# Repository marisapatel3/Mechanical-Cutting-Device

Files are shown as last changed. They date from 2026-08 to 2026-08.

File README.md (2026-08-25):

# Mechanical Cutting Device: Adaptive Fold-Over Slicer

McMaster ENGINEER 1P13, Mar 2022 – Apr 2022.

Ergonomic fold-over slicer designed for a client with Ehlers Danlos Syndrome to reduce joint strain and lateral hand movement during food preparation.

`Autodesk Inventor` `3D Printing` `Woodworking` `Assistive Design` `PLA` 

<p align="center">
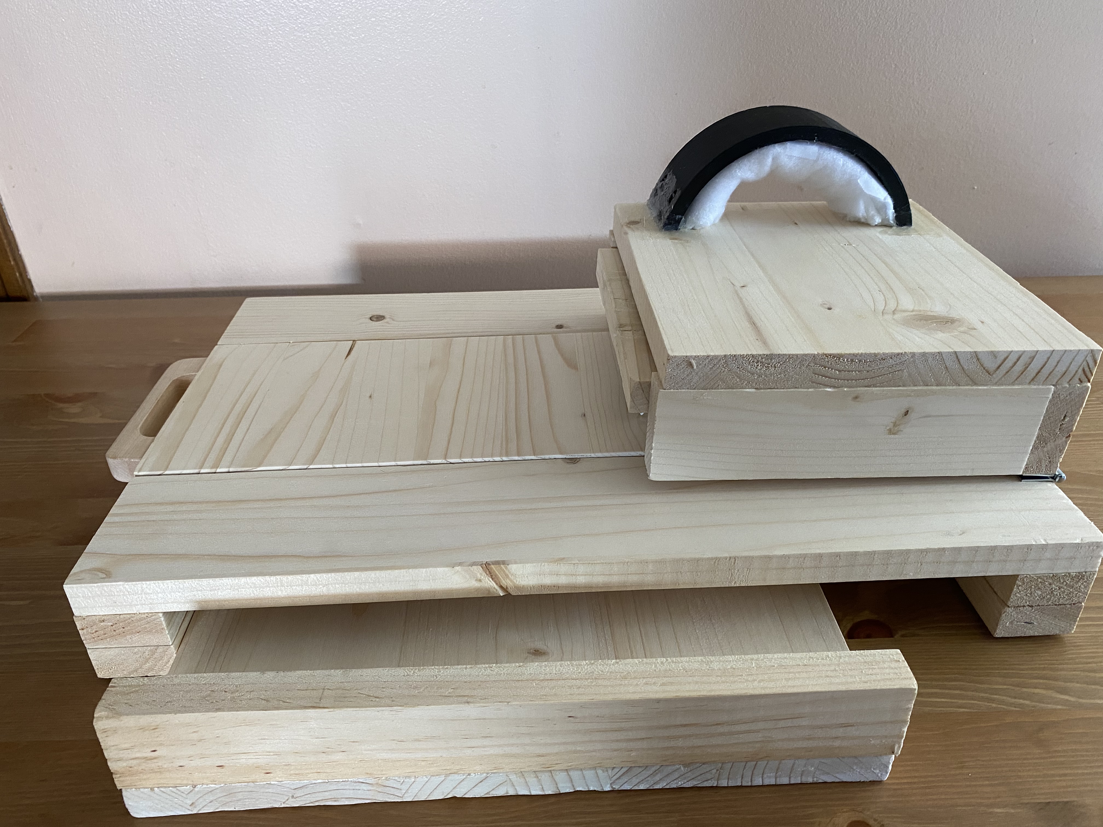
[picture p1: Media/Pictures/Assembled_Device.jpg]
Assembled device
<br>
<em>Fully Assembled Cutting Device with the Cutting Board, Drawer, Slicer, and Strap.</em>
</p>

---

## Table of Contents
- [Overview](#overview)
- [Design Requirements](#design-requirements)
- [Components & Materials](#components--materials)
- [Design Details](#design-details)
  - [1. Hand Support & Ergonomics](#1-hand-support--ergonomics)
  - [2. Cutting Mechanism](#2-cutting-mechanism)
  - [3. Food Collection & Board](#3-food-collection--board)
  - [4. Assembly & Modular Hardware](#4-assembly--modular-hardware)
- [How to Use](#how-to-use)
- [CAD & Engineering Drawings](#cad--engineering-drawings)
- [Results](#results)
- [Limitations & Future Improvements](#limitations--future-improvements)
- [Full Report](#full-report)

---

## Overview

This project was built for a client living with Ehlers Danlos Syndrome (EDS), a connective tissue condition that makes gripping and applying force through the hand joints painful during everyday tasks such as cutting food. Standard knives require bending the fingers around a handle and pushing downward, placing significant strain on the carpometacarpal and metacarpophalangeal joints. The finished device is a fold-over slicer attached to a cutting board, letting the client prepare food with a flat hand placement and without the lateral cutting motion required by a standard knife. Main components include a wooden cutting board with a sliding cutout and drawer, a hinged slicer with a cushioned wrist strap, detachable 3D printed blades, and a modular pin and hinge assembly.

---

## Design Requirements

The device was designed around three main objectives, each tied to a client focused constraint:

| Objective | Constraint |
|---|---|
| Ergonomic | Hand stays flat during operation, with rounded edges and support rather than a device that takes over the client's motion entirely. |
| Lightweight | Overall weight kept under 5 pounds so the client could carry the device easily. |
| Adaptive | Blades detachable and food safe, capable of cutting a range of small food products. |

Requirements were identified through client interviews and direct hand measurements taken early in the design process, and were used to size the slicer strap and hand rest to the client's own hand.

---

## Components & Materials

| Design Component | Material | Quantity | Cost |
|---|---|---|---|
| Cutting Board, Cutout, Cutout Handle, Drawer Handle, Drawer, Slicer, Insert Piece | Wood | 6 | $86.53 |
| Blades | PLA | 3 | $0.00 |
| Slicer Strap | PLA | 1 | $0.00 |
| No-Slip Stoppers | Plastic | 6 | $0.00 |
| Hinges | Metal | 2 | $0.00 |
| Nails | Metal | 8 | $0.00 |
| Slicer Strap Lining | Cotton | 1 | $0.00 |
| **Total Cost** | | | **$86.53** |

Wood formed the main structural components, PLA was 3D printed for the blades and slicer strap for its food safety, durability, and ease of reprinting at home, and metal hinges and nails secured the slicer to the board.

<p align="center">
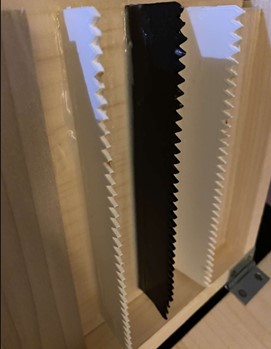
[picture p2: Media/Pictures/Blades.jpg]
  
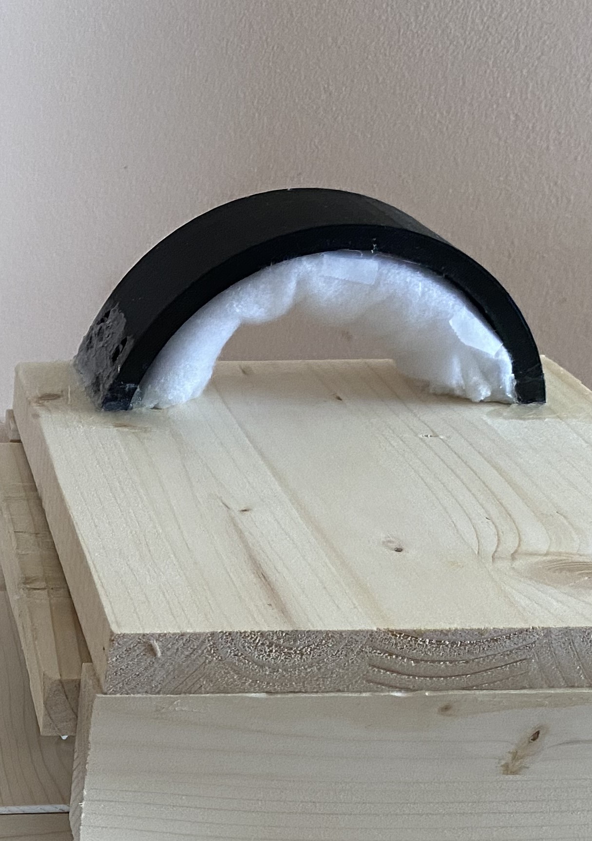
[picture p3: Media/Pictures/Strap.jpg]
  
</p>
<p align="center"><em>3D Printed Blades in a Square Orientation for Cutting Versatility, and the Slicer Strap with Cotton Lining.</em></p>

---

## Design Details

### 1. Hand Support & Ergonomics

- Small divots were sanded into the slicer surface to match the client's hand shape and support the carpometacarpal and metacarpophalangeal joints.
- The slicer strap was sized to about 5 inches wide, using measurements taken directly from the client's hand, so it could fit comfortably with ease.
- Cotton lining under the strap and rounded, sanded edges where the client grips the slicer were incorporated to reduce the pressure points and discomfort during use.

### 2. Cutting Mechanism

- The blades sit in a square orientation within a removable blade insert, allowing versatility while cutting and easy replacement.
- Blades are 3D printed with PLA, chosen for its food safety, durability, and washability while remaining easy to reprint at home if replacement is needed.
- Rotating the slicer downward onto the food, rather than the lateral motion of a standard knife, replaces the standard cutting grip with a single controlled motion.

### 3. Food Collection & Board

- Cut food drops through a sliding cutout in the cutting board into a removable drawer positioned underneath.
- A handle built into the cutout piece allows the client to pull it out easily to retrieve cut food.
- Rubber and plastic no-slip stoppers on the underside of the board keep it stable on kitchen counters during use.

### 4. Assembly & Modular Hardware

- A modular pin and hinge assembly connects the slicer to the cutting board, allowing the slicer to be attached, folded down to cut, and detached for storage.
- All detachable components, including the blades, blade insert, and slicer assembly, are dishwasher safe for cleaning.
- Metal hinges and nails were chosen for their durability, needing to withstand both the weight of the slicer and the downward force of the client's hand during use.

---

## How to Use

1. Place the cutting board on a flat, stable surface.
2. Slide the cutout piece into the board and secure it in place.
3. Attach the slicer to the cutting board by placing the pins through the hinges.
4. Insert the blade assembly, with the blades attached, into the slicer's blade insert.
5. Slide a hand under the slicer strap so it rests flat against the padded, cushioned surface.
6. Grip the sides of the slicer and rotate it downward so the blades cut the food resting on the board below.
7. Pull the cutout handle outward to let the cut food drop into the drawer below, then remove the drawer to retrieve it.

<video src="https://github.com/user-attachments/assets/4832cd9b-568e-46df-9fab-643e632cbbba" controls></video>
<p align="center"><em>Demonstration of the Mechanical Cutting Device being used to cut food, from Attaching the Slicer to Retrieving cut food from the Drawer
</em></p>

---

## CAD & Engineering Drawings

The cutting board and slicer were modeled in Autodesk Inventor using measurements taken from the refined initial prototype, then fabricated through a combination of woodworking and 3D printing.

<p align="center">
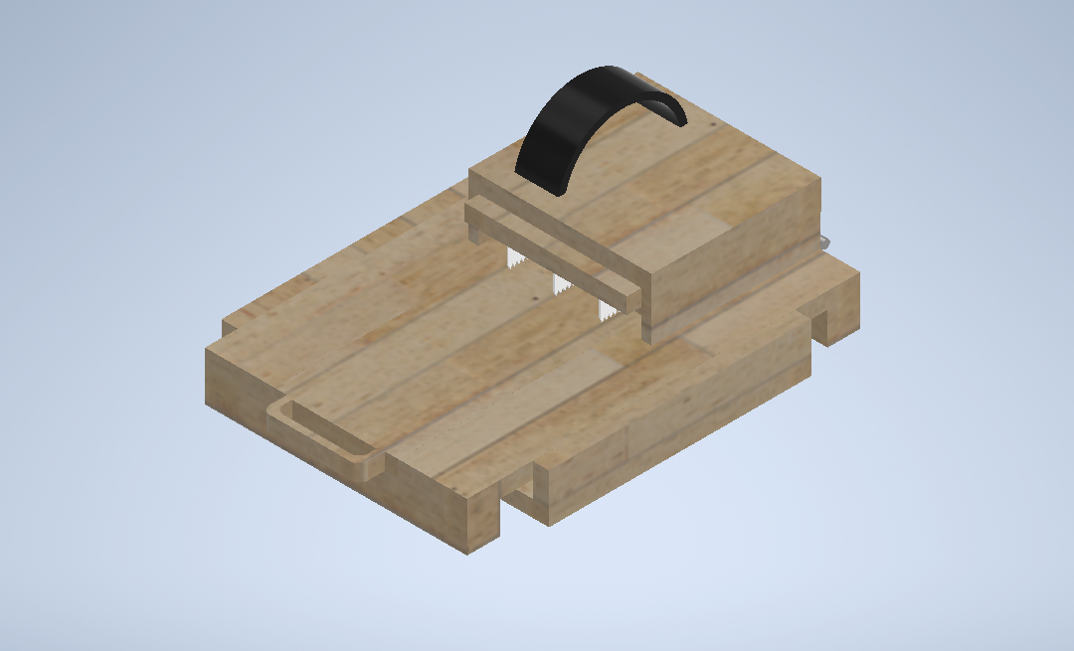
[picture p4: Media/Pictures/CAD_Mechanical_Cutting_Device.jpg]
  
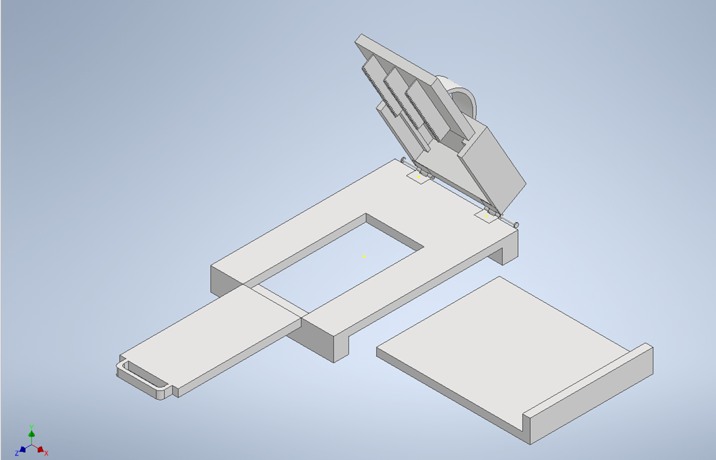
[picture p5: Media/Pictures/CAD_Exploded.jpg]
  
</p>
<p align="center"><em>CAD Model of the Final Refined Prototype Assembled, and with the Components Exploded.</em></p>

<p align="center">
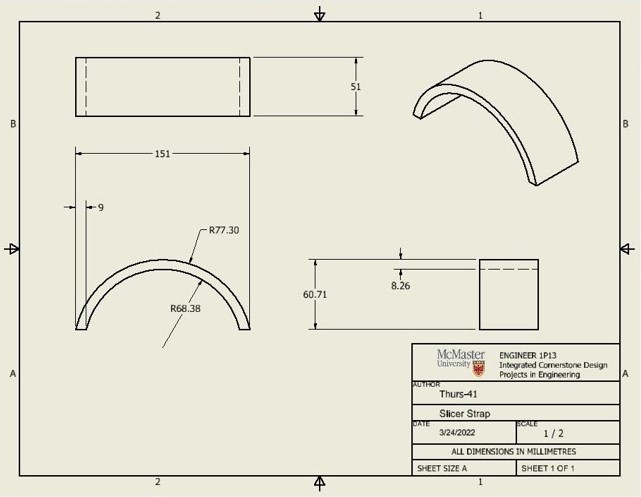
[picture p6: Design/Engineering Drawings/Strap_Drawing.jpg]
  
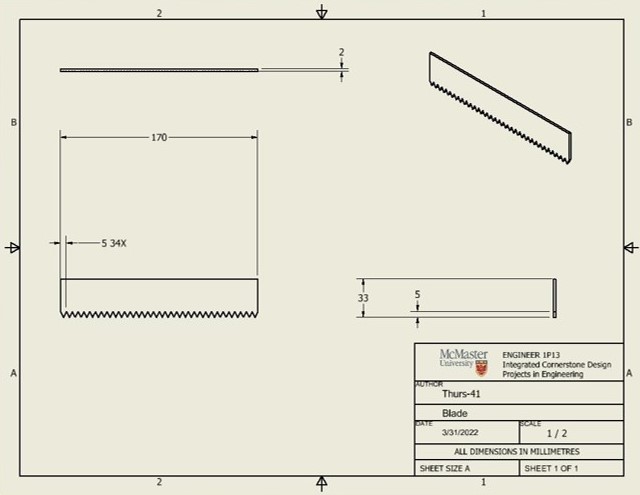
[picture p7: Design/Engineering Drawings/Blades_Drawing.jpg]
  
</p>
<p align="center"><em>Engineering Drawings of Strap (left) and Blades (right), in mm.</em></p>

<p align="center">
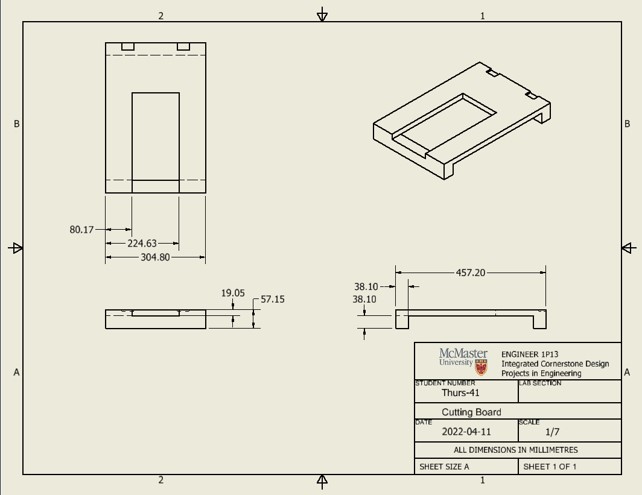
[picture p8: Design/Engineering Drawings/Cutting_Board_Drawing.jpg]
  
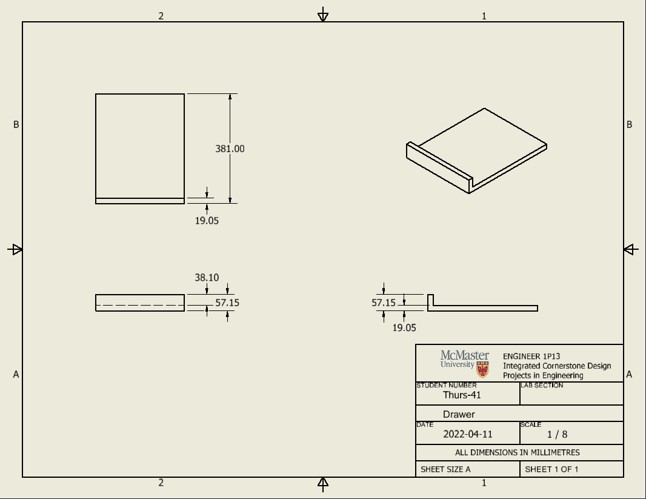
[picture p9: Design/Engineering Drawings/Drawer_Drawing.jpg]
  
</p>
<p align="center"><em>Engineering Drawings of Cutting Board (left) and Drawer (right), in mm.</em></p>

<p align="center">
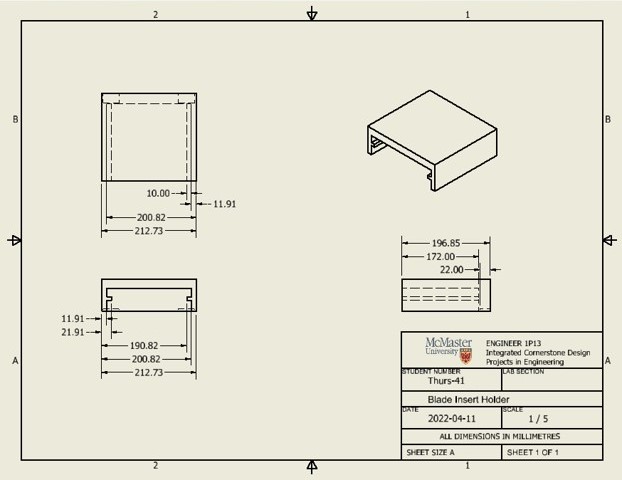
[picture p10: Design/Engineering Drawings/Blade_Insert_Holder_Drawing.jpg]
  
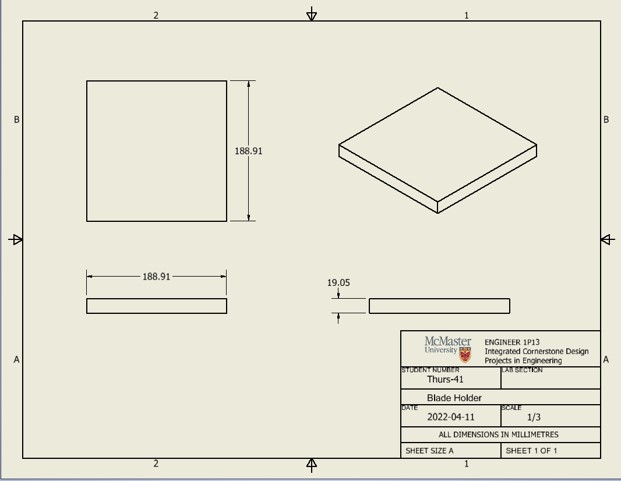
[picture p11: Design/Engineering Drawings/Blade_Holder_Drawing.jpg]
  
</p>
<p align="center"><em>Engineering Drawings of Blade Insert Holder (left) and Blade Holder (right), in mm.</em></p>

---

## Results

- The device successfully functioned as a working assistive cutting tool, allowing the client to prepare food using a flat hand position with reduced lateral movement and joint strain compared to a standard knife.
- Testing with reviewers indicated a lower estimated injury rate than cutting with a regular knife.
- The prototype weighed approximately 2 kilograms, meeting the lightweight objective of staying under 5 pounds.
- Testing confirmed the design could adaptively cut a range of small food products, including bananas, grapes, kiwi, and strawberries.

---

## Limitations & Future Improvements

- Blades were 3D printed with PLA and a serrated edge, which demonstrated the design's functionality, but would need to move to a plastic or metal blade for a sharper, more commercial grade cut.
- No guard or cover was fabricated for the blades due to project time constraints, though it was identified as a valuable safety addition.
- The height of the cutting board was only estimated from the client's body measurements. Having the client test the device directly and adjust for comfort would be a more reliable input.
- An adjustable height mechanism was considered so other members of the client's household could use the device, but was not implemented within the project timeline.
- More food safe materials, such as different cuts or polished wood, were identified as an improvement if given an increased budget.

---

## Full Report

[Read the Full Project Report](Files/Mechanical_Cutting_Device_Report.pdf)

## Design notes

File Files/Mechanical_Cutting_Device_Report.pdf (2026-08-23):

## Project Four – Power in Community:

## Design a Device to Improve a Client’s Daily Living

### ENGINEER 1P13 – Integrated Cornerstone Design Projects

Tutorial T09

Team Thurs-41

Louisa Mueller (muellel)

Muhammad Khan (khanm417)

Wendong Wang (wangw198)

Marisa Patel (patem156)

Submitted: April 11, 2022

1P13 DP-04 Final Report | Tutorial T09 | Team Thurs-41

Table of Contents

Academic Integrity Statement

The student is responsible for performing the required work in an honest manner, without plagiarism and

cheating. Submitting this work with my name and student number is a statement and understanding that this

work is my own and adheres to the Academic Integrity Policy of McMaster University.

Louisa Mueller | 400393319

X

The student is responsible for performing the required work in an honest manner, without plagiarism and

cheating. Submitting this work with my name and student number is a statement and understanding that this

work is my own and adheres to the Academic Integrity Policy of McMaster University.

Muhammad Khan | 400389220

X

The student is responsible for performing the required work in an honest manner, without plagiarism and

cheating. Submitting this work with my name and student number is a statement and understanding that this

work is my own and adheres to the Academic Integrity Policy of McMaster University.

Wendong Wang | 400371495

X

The student is responsible for performing the required work in an honest manner, without plagiarism and

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

work is my own and adheres to the Academic Integrity Policy of McMaster University.

Marisa Patel | 400393635

X

Executive Summary

For the past few weeks, our group has been working to design a device that would aid our client, an

individual who has been struggling with Ehlers-Danlos Syndrome (EDS), a condition that affects the connective

tissue. We had been tasked with coming up with a solution that makes the client’s daily living better, whether

that be some sort of aid while cooking, cleaning or exercising. The basis of our design was to aid our client in

the process of cutting and preparing ingredients to cook. Our proposed solution had to be designed while

keeping in mind some key factors pertaining specifically to our client. These factors included and were not

limited to comfort, ergonomic, reducing lateral movement and strain among many others.

Our team accomplished this by manufacturing the device

that can be seen in Figure 1. Our design worked by first inserting

your hand and securing it under the black wrist strap. The action of

holding a knife can prove to have very awkward placement for one’s fingers which is why decided to keep our

client’s hand flat. To provide comfort, the wrist strap was lined with a soft fabric lining and the resting block

where our clients hand would rest has small divots to provide extra support to the carpometacarpal and

metacarpophalangeal joints. The cutting board itself contained a sliding piece that would provide ease in the

retrieval of food once it had been cut. Once the sliding insert piece was taken out, the food would be stored in

the drawer that can be seen under the cutting board in Figure 1. The bottom of the cutting board had rubber slip

stoppers to increase friction between the cutting board and the surface it was resting on to decrease the

likelihood of the board slipping and causing an injury. As seen in Figure 2, the blades used are in a square

Figure 1. Design

Figure 2. Blade orientation allowing for versatility while cutting. Along with the increased versatility, the blades are easily

replaceable as well due to them being 3D printed with PLA (polylactic acid) filament, which is in fact food safe.

Our proposed solution has multiple benefits for the client. Firstly, our design works to reduce strain on

the user's hand while cutting. This is accomplished by implementing several design considerations. These

include a flat hand placement that will help distribute the load instead of overloading a specific joint in the

hand. The use of small divots also helps with the distribution of the load evenly throughout the client’s hand.

Additionally, introducing 4 detachable components, sliding drawer, insert piece, blade insert and blade holder,

proves to aid in the process of cleaning along with the storage of the device when it is not in use. Finally, the

use of 3D printed blades can prove to be quite beneficial as well. With the use of PLA filament along with a

high infill, not only are the blades food safe, but they are also quite durable as well. Using 3D printed blades

also allows our clients to replace them easily as he has access to a 3D printer enabling him to replace the blades

whenever need be with little cost.

Moving forward, our solution still has ample of

room for improvement. If given more money,

resources and time, our team could focus on

implementing some sort of adjustment that would

allow our client to modify the height of our device.

By doing so, our client would be able to place

different sized drawers under the cutting board. This

would also allow him to find the height that is best

for him which would further increase the comfort.

Furthermore, looking to use more food safe

materials such as different cuts of wood along with

polished wood would be quite beneficial if given an

increased budget. Refining the handle seen in Figure 3 to cater more towards client specifications, such as his

overall hand measurements and what feels most comfortable for him, would further increase the ergonomic

basis of our design.

Figure 3. Slicer Strap

Main Body

Introduction

EDS, short for Ehlers-Danlos Syndrome, is used to describe a variety of connective tissue disorders

which caused the clients’ disabilities to live their normal lives. This is caused by specific gene failures which

weaken the connective tissues, which are sometimes inherited [1]. The common symptoms of EDS include

overly flexible joints, as well as stretchy and fragile skin [2]. According to our client, he is frequently injured

while going about his day-to-day life and many physical therapies such as Tai chi do not seem to help. He also

mentioned how bothered he was in his everyday life while doing common tasks in the kitchen such as cutting.

The common position of holding a knife is to put the handle between thumb and index finger, which uses the

hand component between them to push the knife downwards to cut. This position applies a significant amount

of pressure to both the carpometacarpal and basal carpometacarpal joints [3]. This causes the client with EDS

hard to operate with the common knives in current market. In this case, we decided to design a cutting board for

the client to cut some simple things in the kitchen. The carpometacarpal and basal carpometacarpal joints [3].

The strain placed on these joints causes the client a lot of difficulty when operating knives, which are currently

the main cutting method in the commercial market. We wanted to design a solution that would not require our

client to bend his fingers to grip something such as a knife handle. Therefore, our refined problem statement

was to design an ergonomic means to assist our client, who lives with Ehlers-Danlos syndrome which causes

him to experience a lot of pain, when completing simple daily tasks related to cooking such using a knife. The

means will be designed for use in his home to ease the completion of these tasks, which is an essential function.

The device should be lightweight and versatile. It should also reduce lateral movement of the hand and strain on

the joints that would be experienced without the use of the device. We refer to our design as a fold over slicer

with a cutting board attachment. Some objectives of our design were that it should be lightweight, ergonomic,

and adaptive. These were all important in ensuring the device was user friendly and comfortable for the client to

use, as well as practical so he would be able to cut various kinds of food objects in either a lengthwise or

widthwise orientation. A few constraints of our design were that it needed to be made of food-safe materials, the

user’s hand placement was flat, and the blades were detachable. Since this device is meant to be used in the

kitchen and will encounter food, the materials needed to be food safe. Keeping the user’s hand flat while

operating the device was necessary to remove the significant amount of stress applied to the two hand joints

previously mentioned, which was one of the functions our design aimed to achieve. Making the blades

detachable was also a condition that needed to be met for safety purposes, especially when the device was in storage, so the blades could be stored separately and were not at risk of falling out when the device was being

transferred by the user either into or out of storage.

Conceptual Design

The ideation process began during our introduction lecture with James where we were required to take

notes on his experience with Ehlers-Danlos syndrome and daily tasks he struggles with. After combining all our

notes together, we created a very general initial problem statement avoiding any solution-specific terms: design

a means that makes the client’s day-to-day tasks easier to do by reducing physical strain placed on his joints.

From there, we created an objective tree which helped us develop an idea of how we could ensure our design

achieved its main objectives by incorporating certain design requirements. Additionally, developing a test plan

to determine whether our objectives were being met using specified metrics was especially important to refer to

later in the project when we had a functioning prototype. Creating rough sketches and completing a functional

analysis was extremely helpful for brainstorming purposes as we were able to translate the previous research we

had done into a visual of a potential prototype. Taking these sketches and turning them into a physical prototype

made of whatever materials we had available to us was the most crucial point in our design exploration. We

were able to identify certain features of each team member’s prototype that we liked and that lead to our final

prototype incorporating aspects from all initial prototypes. When points were being assigned to certain designs

in our weighted decision matrix, as seen in Section 2 of Appendix A, we had a clear frontrunner which was a

cutting board design with attachments to hold a knife and food object in place. Naturally, that was one of our

choices to present to the science students during the first design review, alongside the slicer with a handle

model. Our two other design ideas were a resting block to sit on top of a device, as well as a fold-over slicer

with a similar concept to an egg slicer. The feedback we received during the first design review really drew our

attention to materials selection for fabrication, as they needed to be food-safe and ideally dishwasher friendly.

Additionally, incorporating a way for him to be able to cut both lengthwise and widthwise for the slicer with a

handle model was a point made by our TA that altered our final design size-wise so we could include this

refinement. After the conclusion of the first design review, we realized that it would be a lot easier to change

features on the slicer model rather than on the cutting board. This changed our design process greatly as we had

originally thought we would proceed with strictly the cutting board model, but we had the idea to still use a

cutting board with the slicer attached to the board as well. This model, a hybrid of two of our initial prototypes,

was the prototype we brought to the second and final design review. The feedback we received during this

review included adjusting the height of the cutting board, incorporating a drawer feature, making the blades detachable and durable, and finding a way to secure the model to the countertop where it would be used by the

client. We did our best to incorporate as many of these suggestions into our final design as possible to ensure it

was safe and user-friendly for our client.

Final Proposed Design

The final design was officially made after making several iterations to our initial prototype. The final

design is comprised of several components including a cutting board, a cut-out in the cutting board, a handle on

the cut-out, slicer, slicer strap, blades, blade inserts, hinges and pins, nails, drawer, and plastic no-slip stoppers.

Using these components, our team created the alternate method for cutting, which is the fold over slicer.

To operate the device, the user will place the cutting board on a flat surface. The user will slide in the

cut-out and secure in place. Then, the user will attach the slicer to the cutting board by placing the pins through

the hinges. After this, the user will insert the blade insert piece with the blades attached into the slicer

attachment. The user will slide their hand under the slicer strap and lining. After this, the user will grip the sides

of the slicer while being supported by the flat surface of the slicer and the comfortable strap. Using this grip, the

user will rotate the slicer and blades will cut the food product on the cutting board. After cutting the food

product, the user can grab the handle on the cut-out and pull it outwards to allow the food to fall through and

into the drawer. Once the user is finished using the device, they can pull the drawer out and move the food

elsewhere. The blades and blade insert can be removed. The pins in the hinge can be removed to detach the

slicer from the cutting board. These components can be washed in a dishwasher for easy cleaning. This is

essentially the full process of how the design operates.

This design has various specifications. One specification includes the divots sanded into the top of the

slicer piece, which supports the client’s hand joints. The slicer is specifically designed to fit the client’s hand

comfortably on the top of the slicer to reduce any discomfort and lateral movement of his hand joints. Using the

pictures of James’ hands that were provided, we were able to map out the dimensions of his right hand to create

the indents in the correct positions on the slicer [3]. Using this, we ensured that the slicer strap was also about 5

inches wide to make sure his hand can fit under it with ease [3]. We also made the dimensions of the slicer

slightly bigger than James’ hand and wrist to ensure that it can rest comfortably on the slicer while using the

design. We also lined the inside of the slicer strap with cotton to provide a soft layer of support that will be

comfortable for the client’s hand. The area where the client would grip the slicer once his hand is placed under

the strap, is sanded down to create curved/rounded edges to reduce discomfort.

Our final drawings of the design were done on Inventor using the measurements from our refined initial

prototype. They were then turned into 3D parts using mainly the extrude tool so that we could assemble them

into our prototype after they were fabricated. The assembly of our prototype can be seen in Figure 4 below.

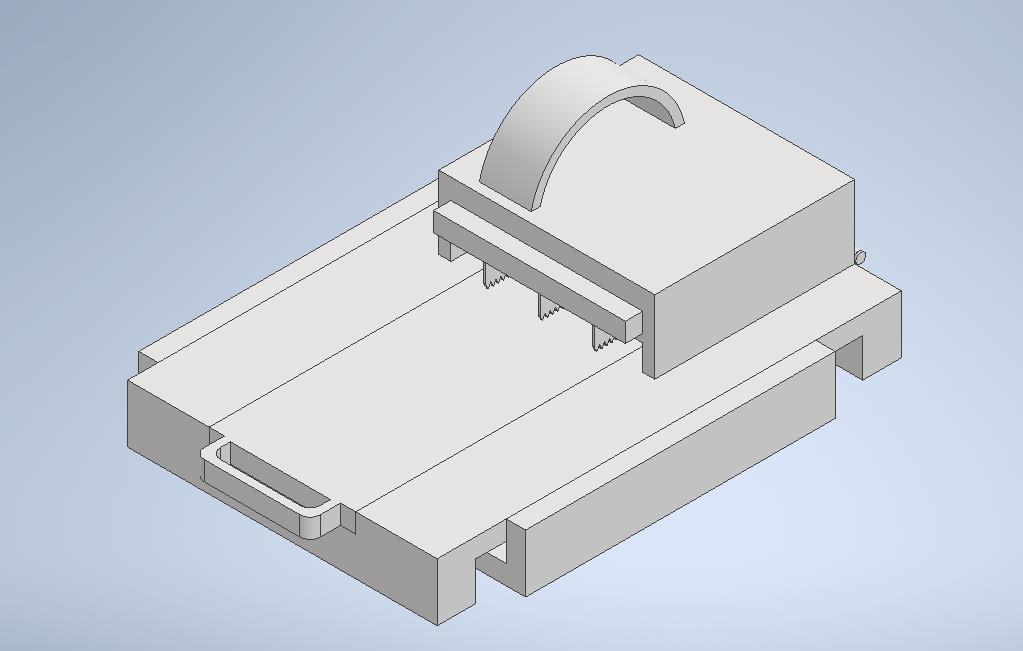
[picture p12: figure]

Figure 4. Assembly in Inventor of all of our prototype’s components with correct measurements

There are various objectives and constraints that our final design met. Our three main objectives were

ergonomic, lightweight, and adaptive. Our design has met these objectives, which were determined by the

metrics associated with them. After testing out the design through various peers including our design reviewers,

we were told that the injury factor of our design or the rate of injury has been lowered compared to using a

regular knife. The estimated weight of the prototype is around 2 kilograms, which was measured using a scale.

This means that our design is also quite lightweight. Our design is also adaptive as it can cut various small sized

food products, as we have tested the design with various fruits such as bananas, grapes, kiwi, and strawberries.

Some constraints we came up for our design include having it weight less then 5 pounds. This is because it

should be easy for the client to carry the device.

There were a few construction methods we used to fabricate the final design. This included a

combination of 3D printing and woodworking. We decided to 3D print the blades and the slicer strap

components of the design. The material used was PLA, which is easy to clean. This is why we chose this

material. The blades will be making contact with the food products, so these would need to be easily cleansed.

The client also has access to 3D printing at his residence, which means we could replace the blades by printing

new ones. From touching food products, the client’s hands could get dirty as would the slicer strap. The PLA

would be easy to clean for the client. We used metal nails and hinges to attach the slicer to the cutting board.

We used metal as the material needs to be sufficiently durable to withstands the weight of the slicer on the

cutting board and the client’s hand on the top of the slicer. We used layers of cotton material to line the

underside of the slicer strap. This is because cotton is a very smooth and soft material, which will be able to

support James’ hand and provide comfort while the strap secures his hand in place. The bottom of the cutting

board has stoppers to ensure the cutting board stays in place. We used plastic stoppers to ensure they grip

kitchen counters nicely. The main components of the design including the cutting board, cut-out, cut-out handle,

drawer, slicer, and blade insert piece were all made out of wood. After purchases various sizes of wood from

Home Depot, we used a miter saw to cut the pieces of wood to the correct dimensions. Using wood glue, we

pieced together the wood. This is the construction and fabrication process we used to create our final design.

Table 1. Bills of Materials

Design Component | Material | Quantity | Cost for Parts ($)

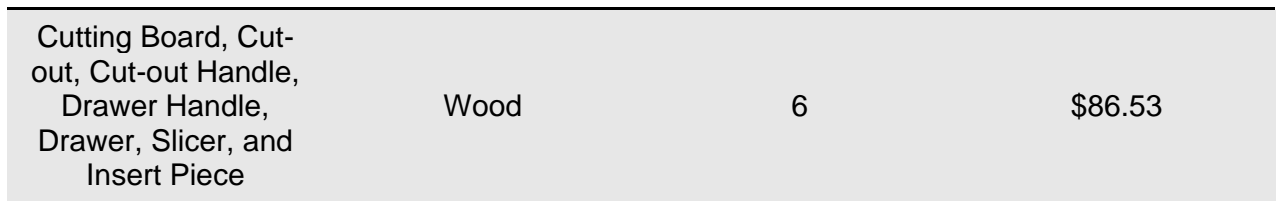
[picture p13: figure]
Cutting Board, Cut- out, Cut-out Handle, Drawer Handle, Drawer, Slicer, and Insert Piece; Wood

Blades | PLA | 3 | $0.00
Slicer Strap | PLA | 1 | $0.00
No Slip Stoppers | Plastic | 6 | $0.00
Hinges | Metal | 2 | $0.00
Nails | Metal | 8 | $0.00
Slicer Strap Lining | Cotton | 1 | $0.00
Total Cost | | | $86.53

Conclusions

If we were given more time, a few steps we would take to improve our device would be researching

other materials to fabricate blades out of, creating a guard or cover for the blades, and experimenting with the

height of the cutting board. Due to a resource limitation, we were only able to 3D print the blades using PLA filament with a serrated edge, which worked for the purposes of showing the functionality of our design.

However, to make this product more commercial grade we would have investigated using either plastic or metal

knife blades which would have been sharper and easier to cut with. Creating a cover or guard for the blades was

another idea we had but were not able to create due to a lack of time left in the project. Making a functional

prototype was our main goal and although a guard would have been a great safety feature, we chose to focus our

time and energy on the fabrication of the cutting board and slicer.

Additionally, experimenting with the height of the cutting board was a metric we talked about to test

how ergonomic our design would be for the client to use. We did not want the board to be too tall or short as

that would cause unnecessary strain on the client’s back and shoulders by him having to either hunch over or

stand too upright while operating the device. Therefore, finding an equilibrium height where his back and

shoulders would not have to be over engaged when using the device would be ideal. We were only able to

estimate this approximate height of the cutting board given his body measurements and some research done but

having him test out the device and tell us what felt most comfortable would be the most ideal design input.

Another option we considered later in the project was making the height of the cutting board adjustable so other

people in his household could use it as well, but again we did not have the time to explore this design

alternative.

Reflecting on the few weeks during which this project took place, our view of the design process was

altered quite a bit. We realized that having to take a step back in the process and rethink some previous design

decisions is not necessarily bad and is sometimes needed to better understand the problem being dealt with. The

most important lesson we learned about team dynamics is that communicating openly with your team members

is the key to success. Talking through any potential ideas or concerns we had with the design was always

welcomed and often lead to others sharing their ideas about modifications that could better our design overall.

An interesting feature about our final prototype was that it was a combination of two of our initial prototypes,

which would not have occurred without a collaborative effort between all group members to bring those two

ideas together and turn them into a functional design. Even though two ideas meant to achieve the same task

may seem quite different in their own ways, it is possible to fuse them together into a single design to solve a

problem in a more well-rounded manner.

References:

[1] “Treating Ehlers-Danlos Syndrome (EDS) Hypermobility.”

https://www.3pointproducts.com/blog/health-arthritis-finger-and-toe-conditions/treating-ehlers-danlos-

syndromeeds-hyperrmobility (https://www.3pointproducts.com/blog/health-arthritis-finger-and-toe-conditions/treating-ehlers-danlos-syndromeeds-hyperrmobility) (Accessed Mar. 06, 2022).

[2] “Physical Therapy, Exercise and Braces for People with EDS or HSD Section 1: For Patients”.
[3] “Braces for EDS - Just Sparkle.” https://justsparklejlm.com/2013/08/braces-for-eds.html (Accessed Mar.

06, 2022).

[4] Faculty of Engineering, “Project Four: Power in Community” [Online]. Available:

(https://avenue.mcmaster.ca/). [Accessed Mar. 9, 2022].

Source Materials Database:

[5] T. Pelc, “Assistive devices for the hand: Small joint protection,” Hospital for Special Surgery [Online].

Available: https://www.hss.edu/conditions_assistive-devices-for-the-hand-small-joint-protection.asp.

[Accessed: 07-Mar-2022].

[6] H. P. Levy, “Hypermobile Ehlers-Danlos syndrome,” Gene Reviews [Online]. 21-Jun-2018. [Online].

Available: https://www.ncbi.nlm.nih.gov/books/NBK1279/. [Accessed: 07-Mar-2022].

[7] J. L. Scully, “What is a disease?,” EMBO reports [Online]. Jul. 2004. Available:

https://www.ncbi.nlm.nih.gov/pmc/articles/PMC1299105/.

[8] P. Beighton, H. A. Bird, and R. Grahame, Hypermobility of joints. New York: Springer, 2012.
[9] “Ergonomics definition & meaning,” Merriam-Webster. [Online]. Available: https://www.merriam-

webster.com/dictionary/ergonomics. (https://www.merriam-webster.com/dictionary/ergonomics) [Accessed: 12-Mar-2022].

[10] J. Croasmun, “Is that product ergonomic?,” Sustainable Ergonomics Systems, 08-Oct-2004. [Online].

Available: https://ergoweb.com/is-that-product-ergonomic/. [Accessed: 12-Mar-2022].

[11] S. D. Jepsen, “Secondary injury prevention: Using braces to reduce joint injuries,” Ohioline, 08-Nov-

2013. [Online]. Available: https://ohioline.osu.edu/factsheet/AEX-

982.8#:~:text=Braces%20help%20support%20the%20joint,with%20the%20help%20of%20braces. (https://ohioline.osu.edu/factsheet/AEX-982.8)

[Accessed: 12-Mar-2022].

[12] A. Grande, “How knee support works: Focus physiotherapy,” Physiotherapy, Rehabilitation & Sports

Injury Clinic, 12-Mar-2021. [Online]. Available: https://www.focusphysiotherapy.com/how-knee-

support- (https://www.focusphysiotherapy.com/how-knee-support-works/)

works/#:~:text=When%20a%20person%20puts%20their,joint%2C%20preventing%20a%20recurring%

20strain. (https://www.focusphysiotherapy.com/how-knee-support-works/) [Accessed: 12-Mar-2022].

[13] M. C. Staff, “Knee braces for osteoarthritis,” Mayo Clinic, 20-May-2021. [Online]. Available:

https://www.mayoclinic.org/tests-procedures/knee-braces/about/pac-20384791. [Accessed: 12-Mar-

2022].

Appendix A – Supporting documents

Section 1

Figure 5. Objective Tree

Figure 6. Measurements of client’s right hand (from entry [4] in the List of References)

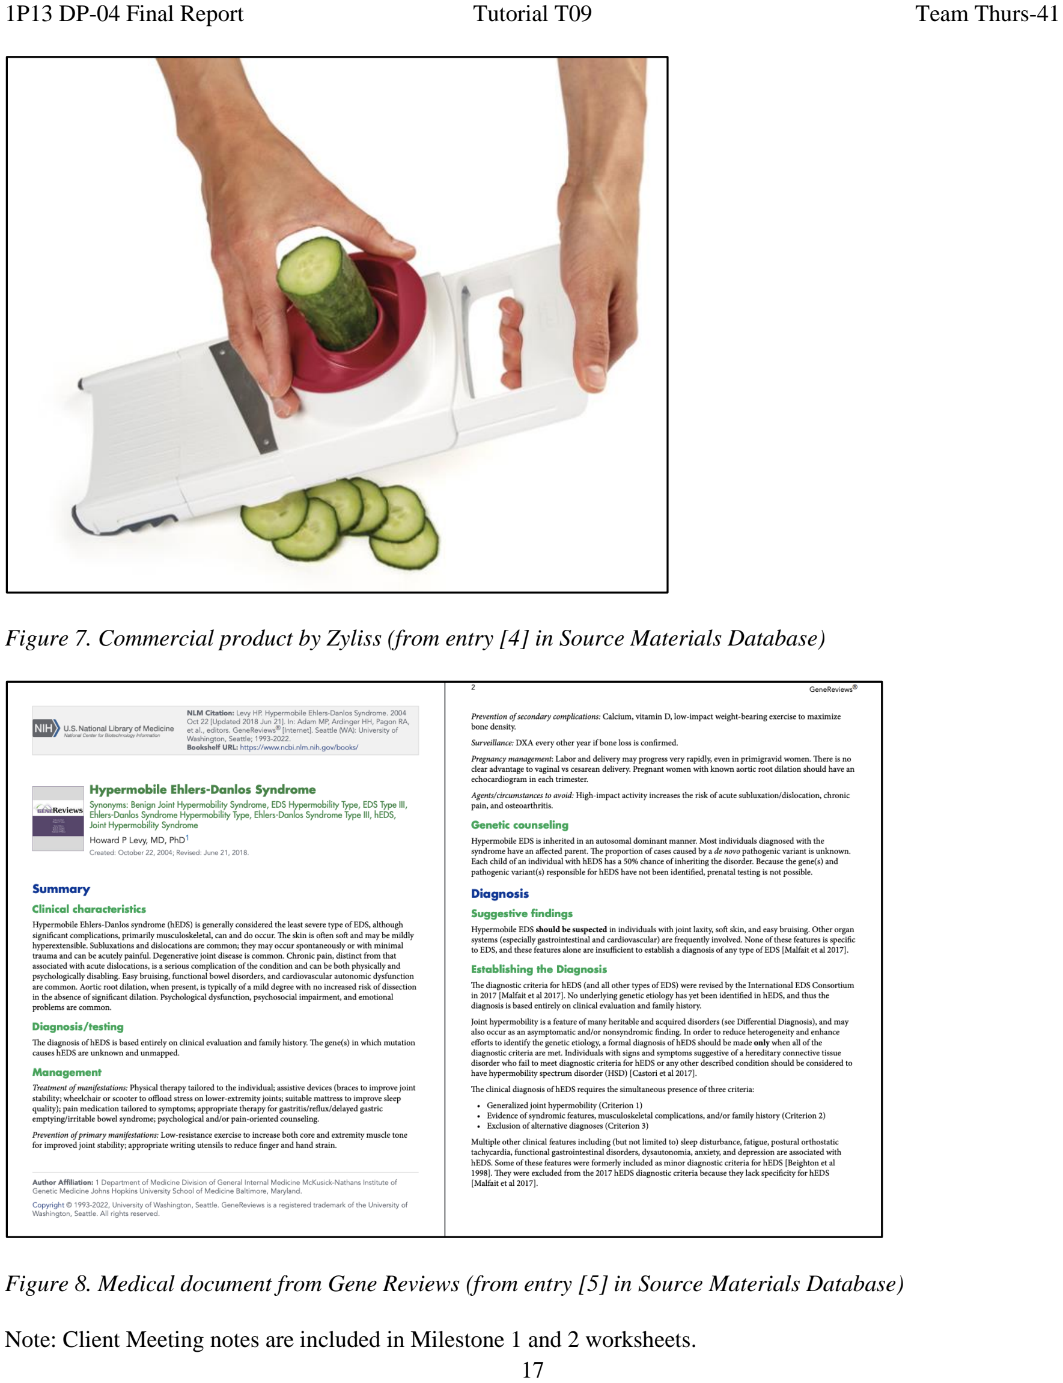
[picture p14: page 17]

Figure 7. Commercial product by Zyliss (from entry [4] in Source Materials Database)

Figure 8. Medical document from Gene Reviews (from entry [5] in Source Materials Database)

Note: Client Meeting notes are included in Milestone 1 and 2 worksheets.

Section 2

Table 2. Weighted Decision Matrix

Table 3. Morph Chart

Note: Initial Concept Sketches are included in the Milestone 2 worksheet.

Note: Design review notes are included in the Milestone 3 (1st review) and Milestone 4 (2nd review) worksheets.

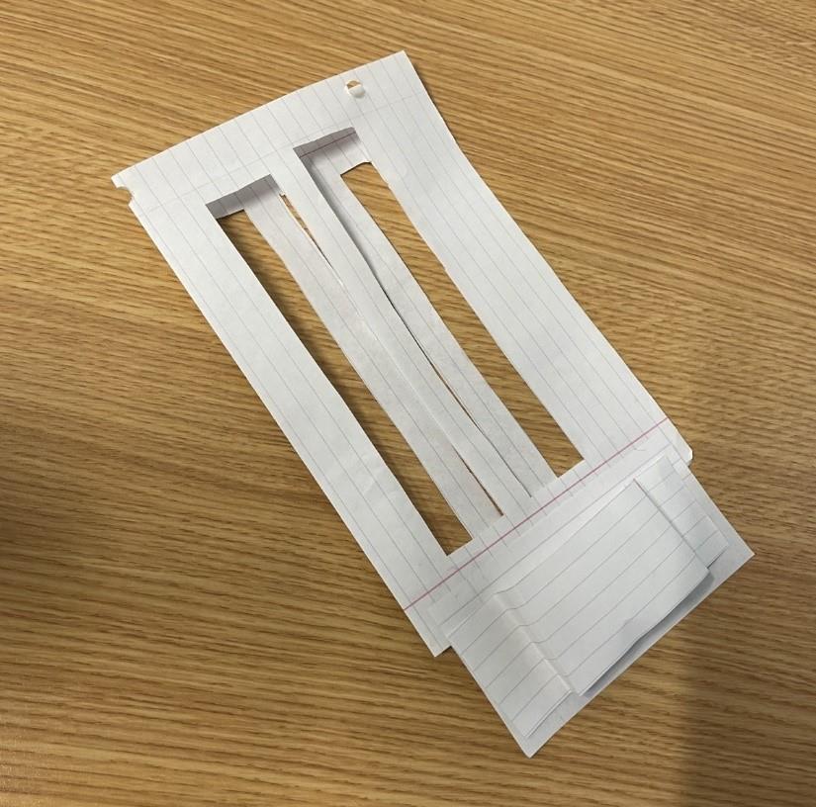
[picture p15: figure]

Figure 9. Refined Concept Initial Prototype #1

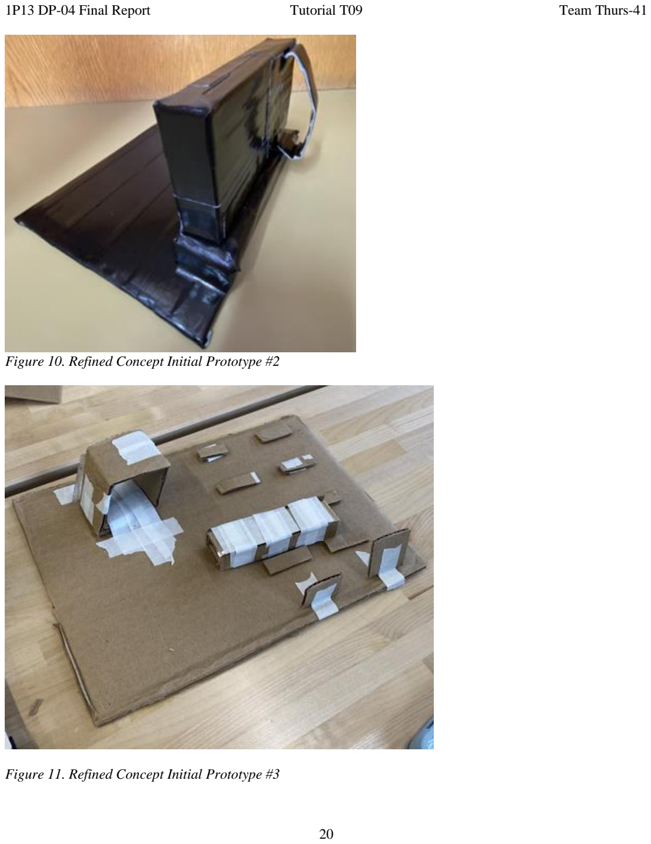
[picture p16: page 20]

Figure 10. Refined Concept Initial Prototype #2

Figure 11. Refined Concept Initial Prototype #3

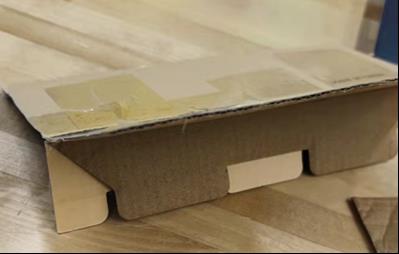
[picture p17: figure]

Figure 12. Refined Concept Initial Prototype #4

Figure 13. Refined Initial Prototype (for design review 2)

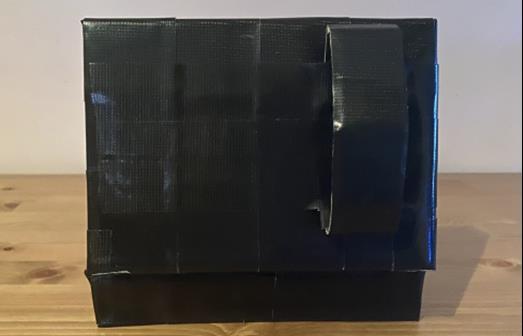
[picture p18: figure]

Figure 14. Refined Initial Prototype (for design review 2)

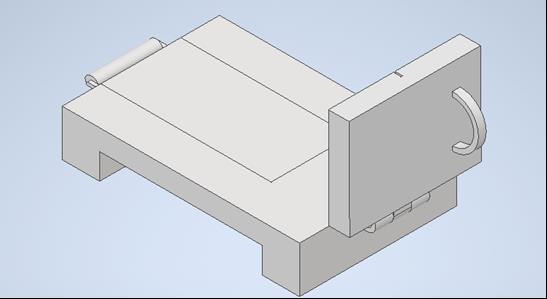
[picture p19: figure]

Figure 15. CAD model of Refined Initial Prototype

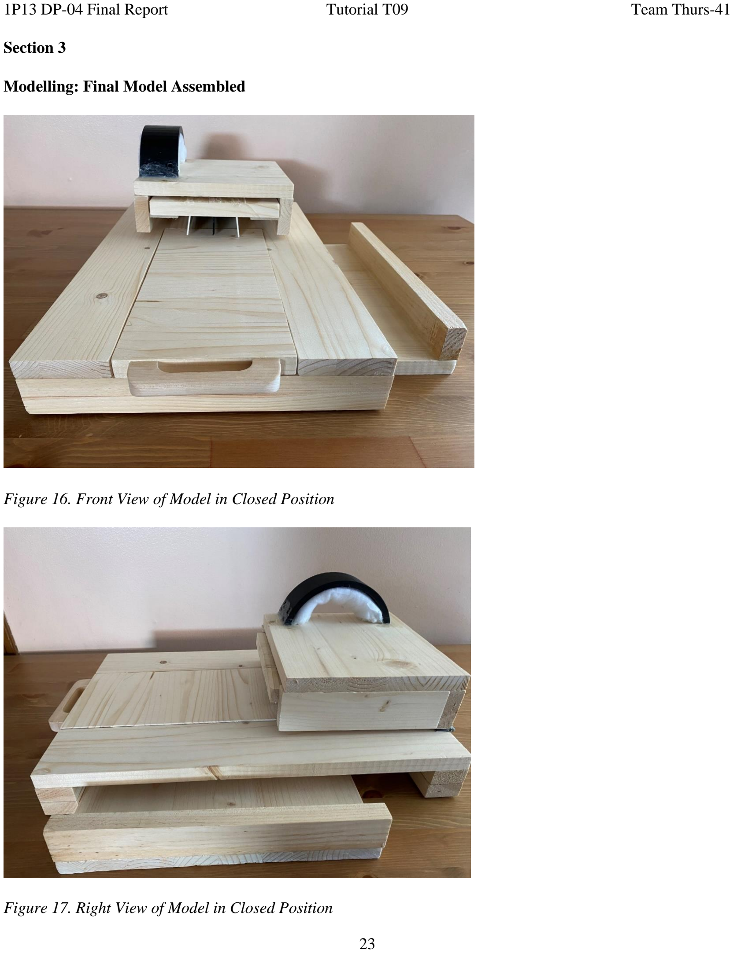
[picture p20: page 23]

Section 3

Modelling: Final Model Assembled

Figure 16. Front View of Model in Closed Position

Figure 17. Right View of Model in Closed Position

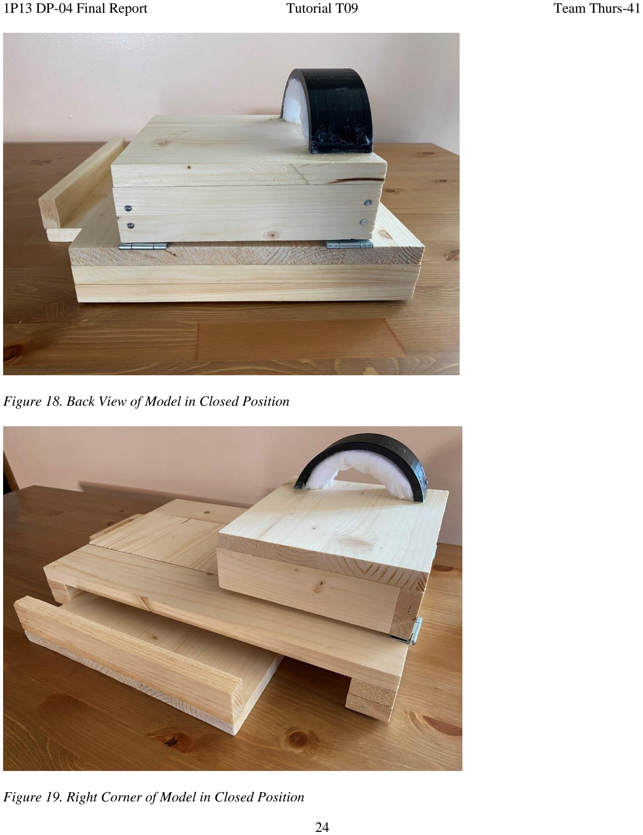
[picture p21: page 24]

Figure 18. Back View of Model in Closed Position

Figure 19. Right Corner of Model in Closed Position

Figure 20. Front View of Model in Opened Position

Figure 21. Right View of Model in Opened Position

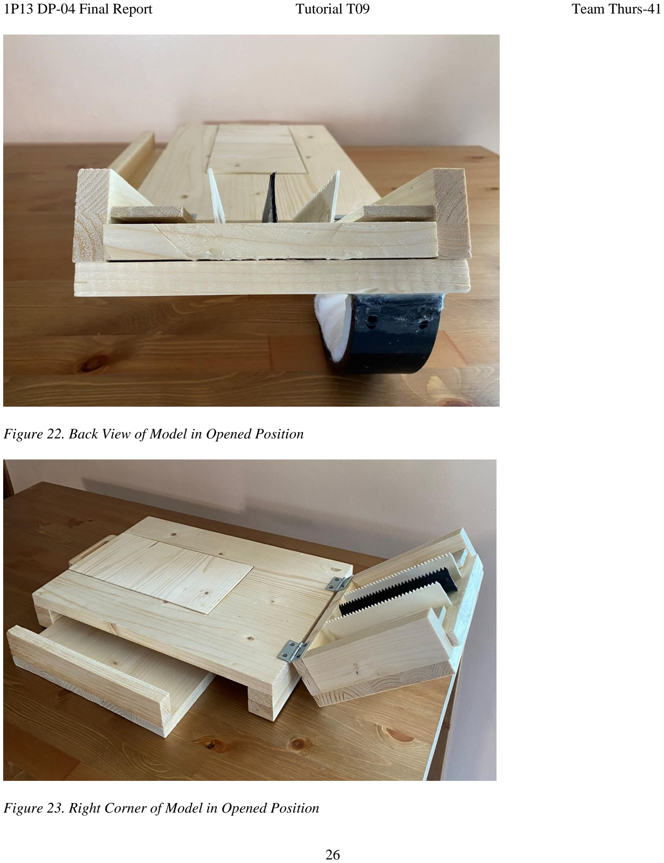
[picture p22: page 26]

Figure 22. Back View of Model in Opened Position

Figure 23. Right Corner of Model in Opened Position

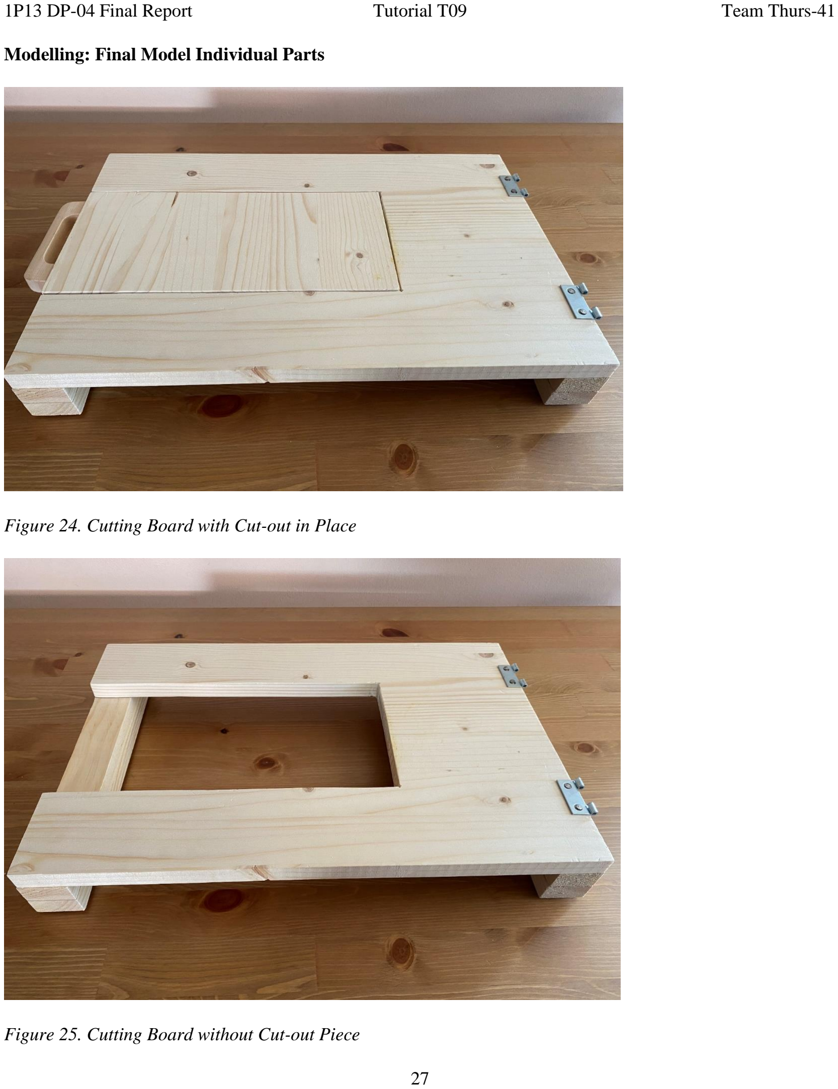
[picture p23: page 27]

Modelling: Final Model Individual Parts

Figure 24. Cutting Board with Cut-out in Place

Figure 25. Cutting Board without Cut-out Piece

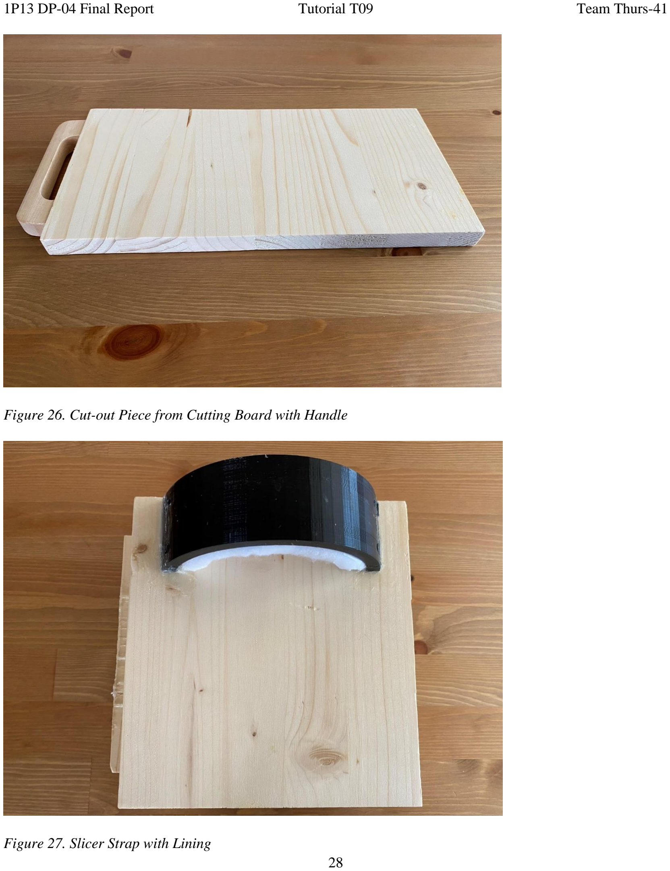
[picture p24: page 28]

Figure 26. Cut-out Piece from Cutting Board with Handle

Figure 27. Slicer Strap with Lining

Figure 28. Slicer with Blade Insert Piece

Figure 29. Slicer without Blade Insert Piece

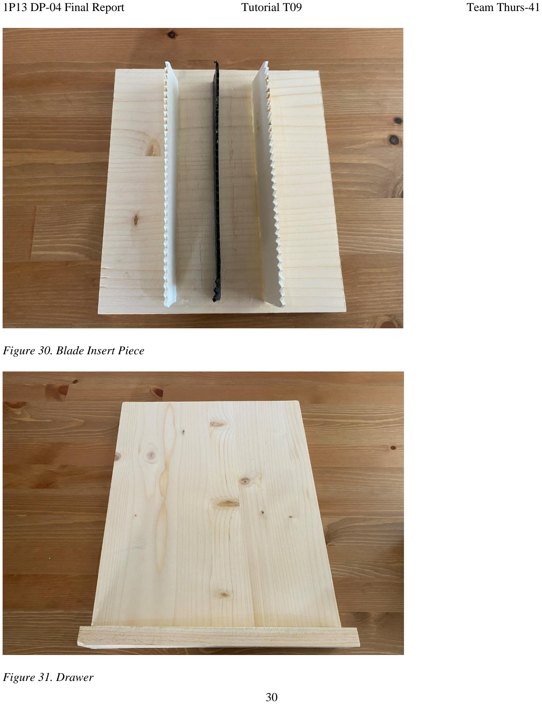
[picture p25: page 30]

Figure 30. Blade Insert Piece

Figure 31. Drawer

Modelling: AutoDesk Inventor Assembly of Parts

Figure 32. CAD model of Final Refined Prototype

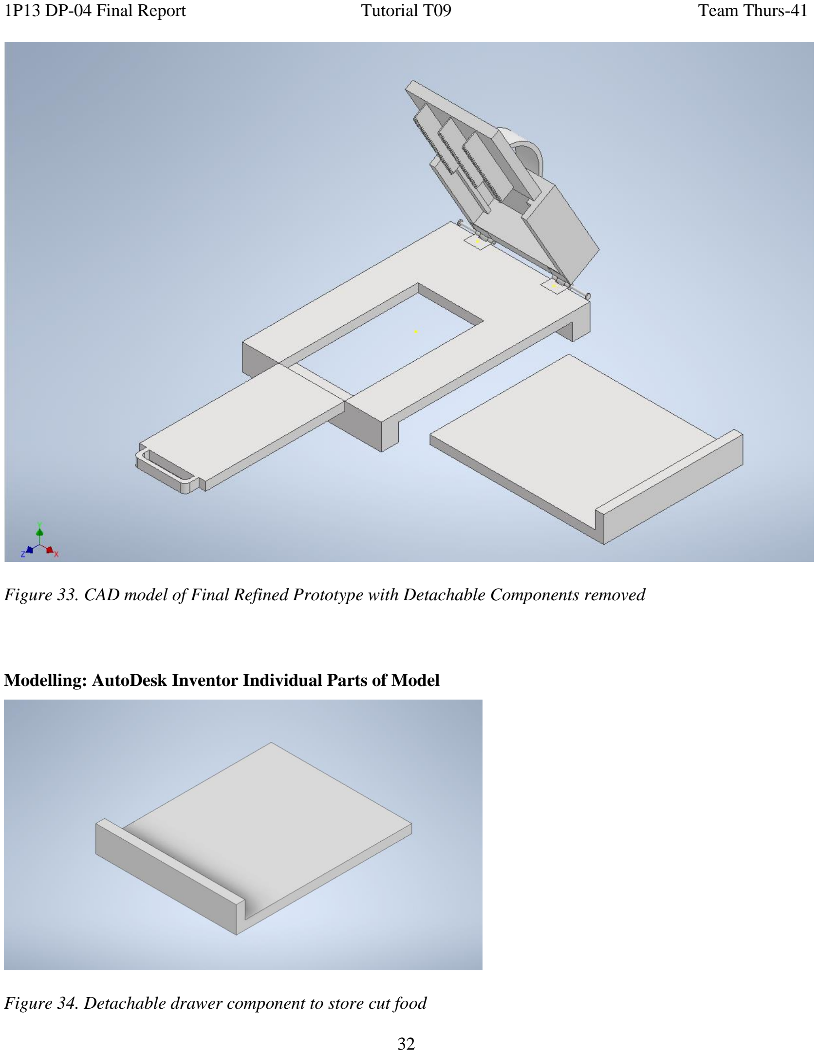
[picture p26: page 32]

Figure 33. CAD model of Final Refined Prototype with Detachable Components removed

Modelling: AutoDesk Inventor Individual Parts of Model

Figure 34. Detachable drawer component to store cut food

Figure 35. Detachable cut-out in cutting board to remove cut food

Figure 36. Slicer insert that the blades are attached to

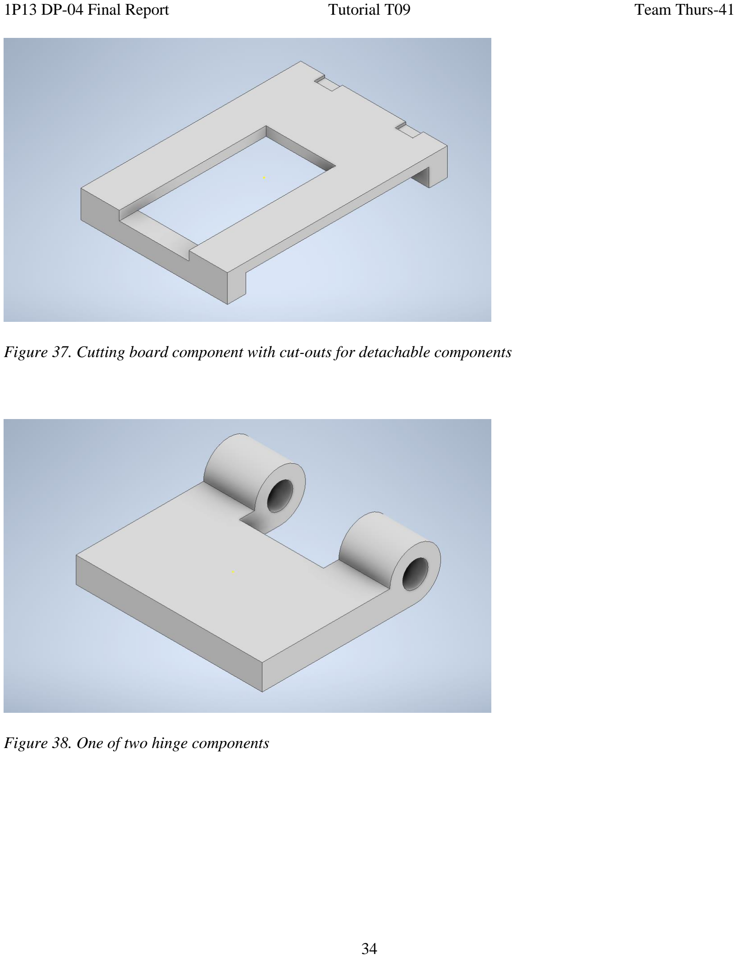
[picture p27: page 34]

Figure 37. Cutting board component with cut-outs for detachable components

Figure 38. One of two hinge components

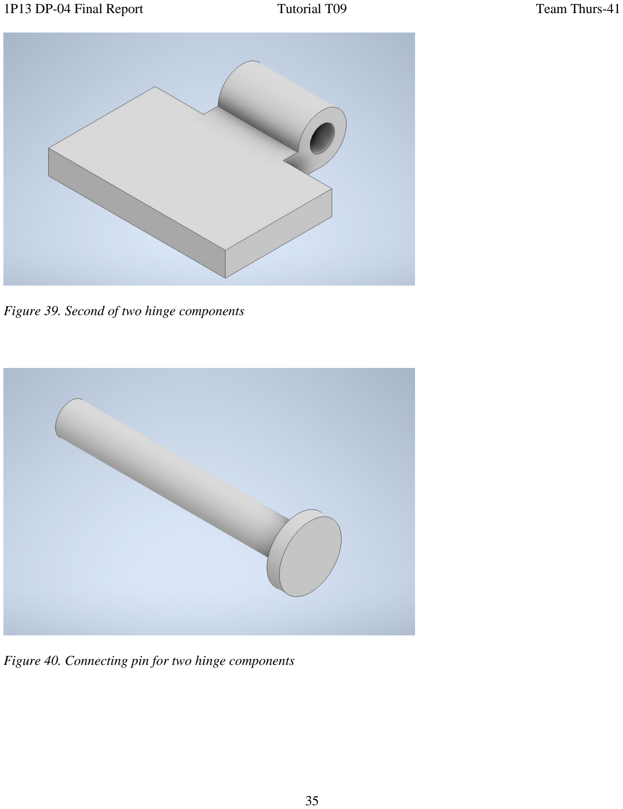
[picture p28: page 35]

Figure 39. Second of two hinge components

Figure 40. Connecting pin for two hinge components

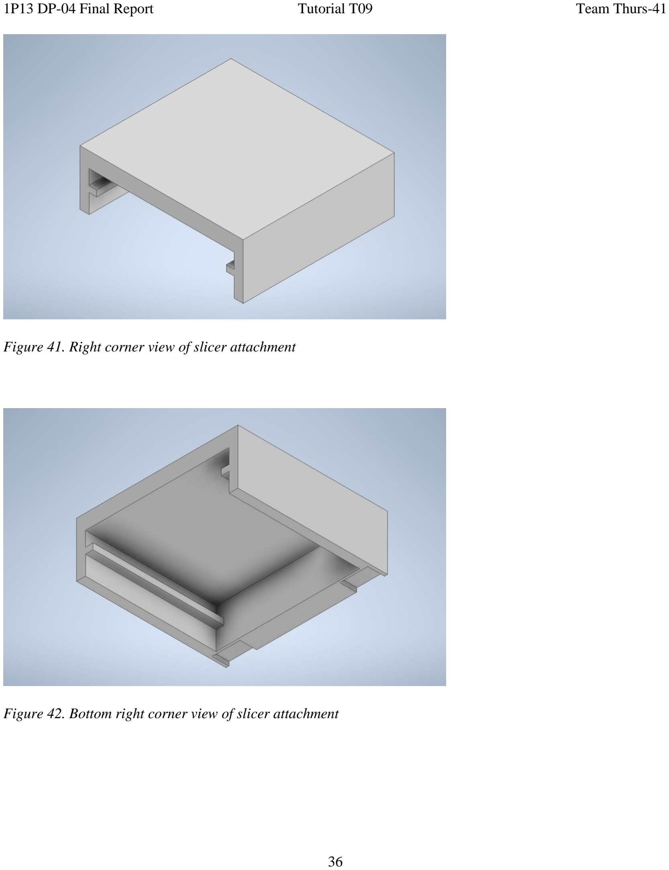
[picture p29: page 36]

Figure 41. Right corner view of slicer attachment

Figure 42. Bottom right corner view of slicer attachment

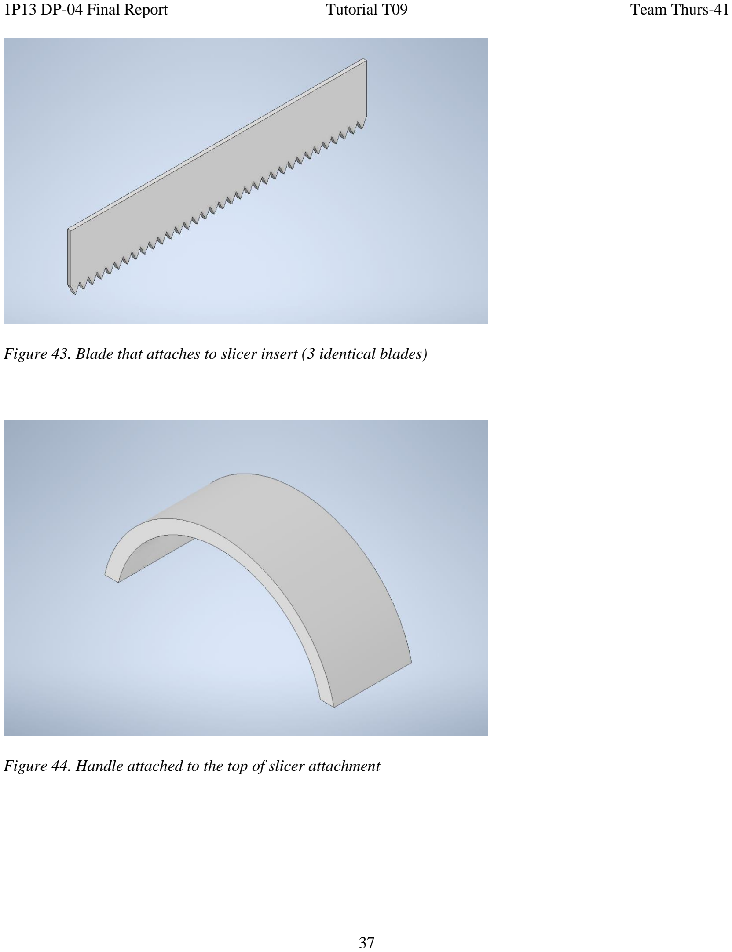
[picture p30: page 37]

Figure 43. Blade that attaches to slicer insert (3 identical blades)

Figure 44. Handle attached to the top of slicer attachment

Modelling: Engineering Drawings

Figure 45. Engineering Drawing of Slicer Strap

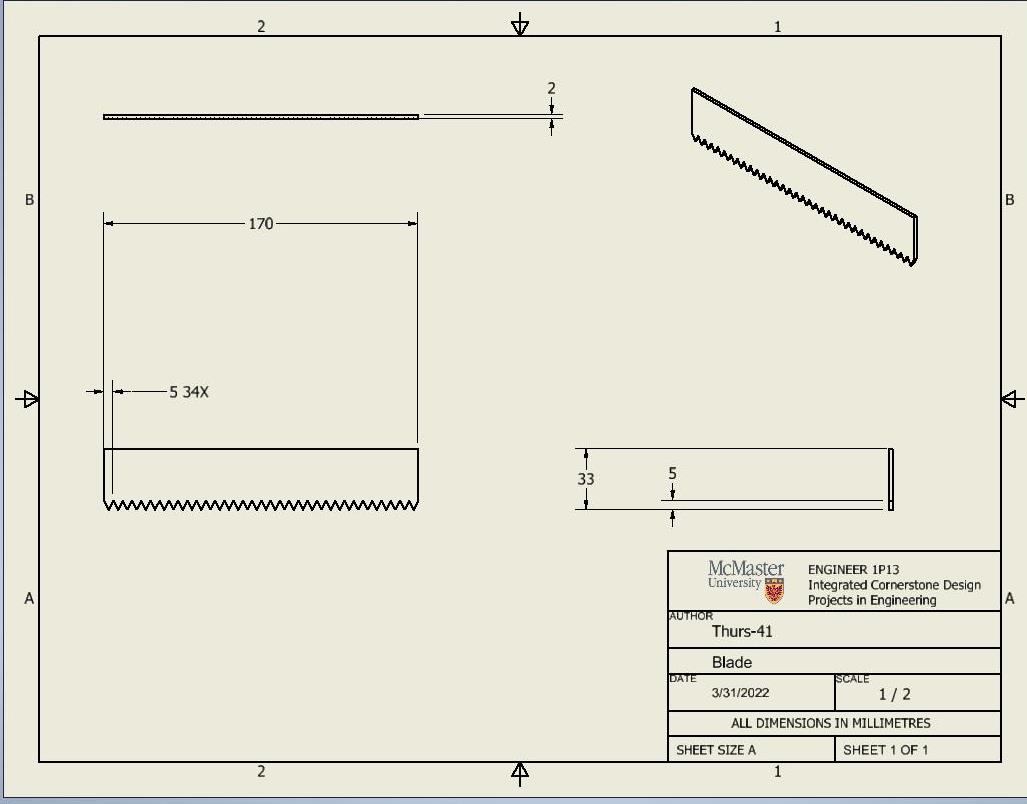
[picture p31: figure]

Figure 46. Engineering Drawing of Blades

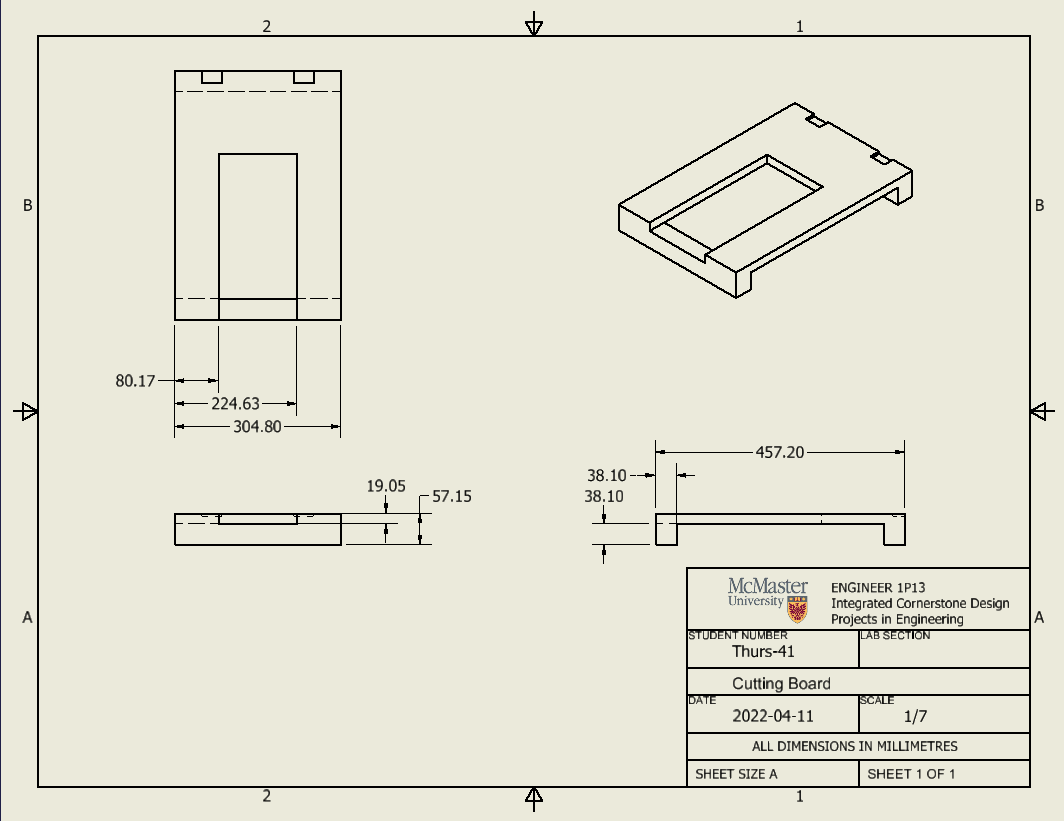
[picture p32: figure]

Figure 47. Engineering Drawing of Cutting Board

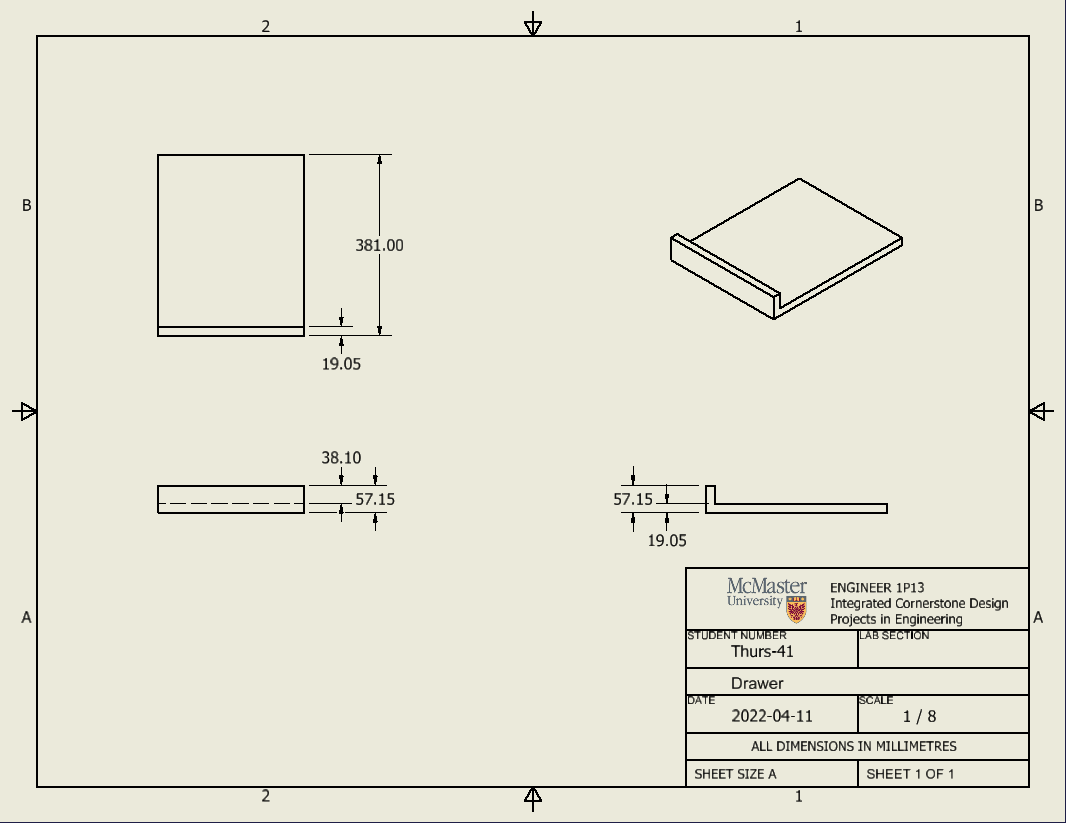
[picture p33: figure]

Figure 48. Engineering Drawing of Drawer

Figure 49. Engineering Drawing of Blade Insert Holder

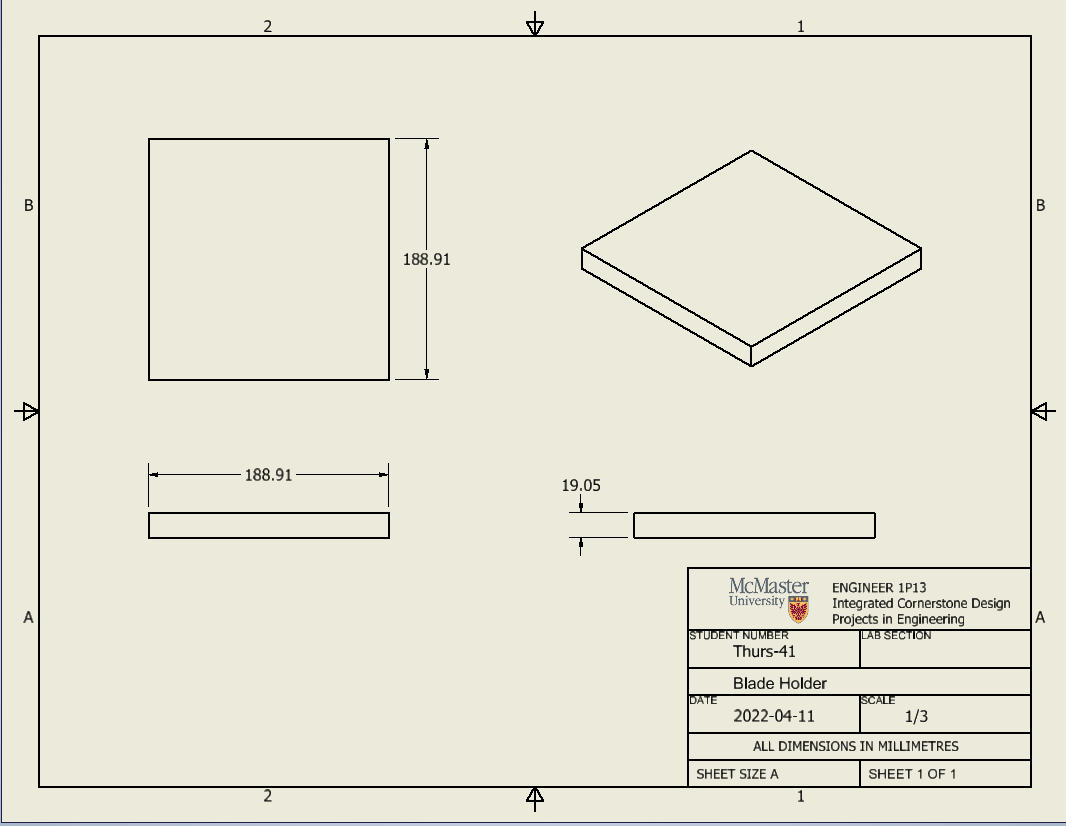
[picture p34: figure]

Figure 50. Engineering Drawing of Blade Holder

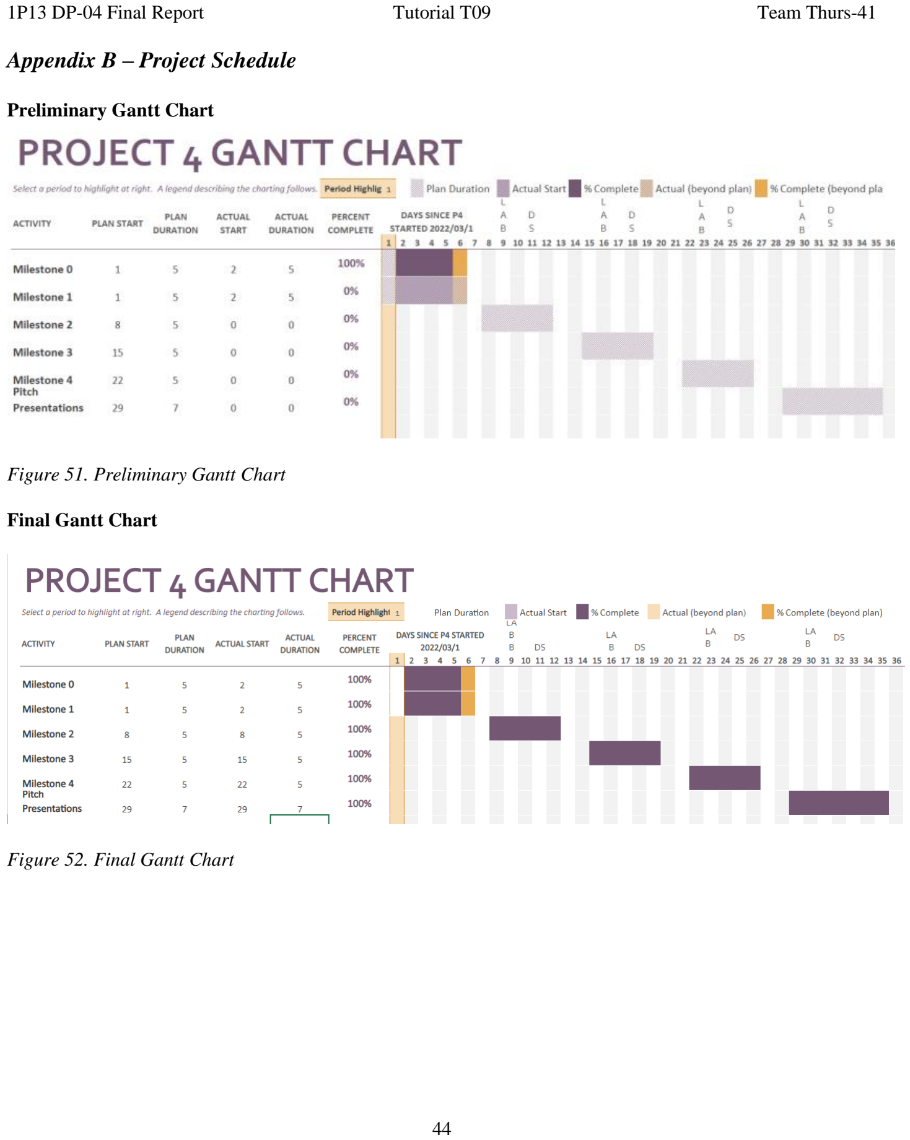
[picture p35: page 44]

Appendix B – Project Schedule

Preliminary Gantt Chart

Figure 51. Preliminary Gantt Chart

Final Gantt Chart

Figure 52. Final Gantt Chart

Logbook of Additional Meetings and Discussions

Date | Communica tion Type | Time | Location | Members present | Topic | Notes
3/1/22 | Meeting | 11:30 am – 12:00 pm | ETB-125 | Louisa Mueller, Muhammad Khan, Wendong Wang, Marisa Patel | Milestone 0&1 | -completed the client notes -finished up milestones
3/5/22 | Discussion | 7:00 pm – 7:30 pm | Microsoft Teams | Louisa Mueller, Muhammad Khan, Wendong Wang, Marisa Patel | Milestone 0&1 | -packed up the milestones -discussed plans about the design
3/8/22 | Discussion | 11:30 am – 12:00 pm | ETB-125 | Louisa Mueller, Muhammad Khan, Wendong Wang, Marisa Patel | Milestone 2 | -finished second client note -wrote the refined problem statement
3/10/2 2 | Meeting | 2:00 pm – 3:30 pm | ABB-C419 | Louisa Mueller, Muhammad Khan, Wendong Wang, Marisa Patel | Milestone 2 | -thought about the initial prototype of the design
3/15/2 2 | Discussion | 11:30 am – 12:00 pm | ETB-125 | Louisa Mueller, Muhammad Khan, Wendong Wang, Marisa Patel | Milestone 3 | -finished the initial prototype -completed decision matrix
3/17/2 2 | Meeting | 2:00 pm – 3:30 pm | ABB-C419 | Louisa Mueller, Muhammad Khan, Wendong Wang, Marisa Patel | Milestone 3 | -participated in the design review -talked about how to fix the problems with blades and boards
3/22/2 2 | Discussion | 11:30 am – 12:00 pm | ETB-125 | Louisa Mueller, Muhammad Khan, Wendong Wang, Marisa Patel | Milestone 4 | -made a test plan -refined the initial prototype
3/24/2 2 | Meeting | 2:00 pm – 3:30 pm | ABB-C419 | Louisa Mueller, Muhammad Khan, Wendong Wang, Marisa Patel | Milestone 4 | -participated in the second design review -gained feedbacks -refined prototype
3/19/2 2 | Discussion | 11:30 am – 12:00 pm | ETB-125 | Louisa Mueller, Muhammad Khan, Wendong Wang, Marisa Patel | Design refinement | -discussed about some specific dimensions
3/31/2 2 | Meeting | 2:00 pm – 3:30 pm | ABB-C419 | Louisa Mueller, Muhammad Khan, Wendong Wang, Marisa Patel | Design refinement | -created a solid model of the design -decided which component requires 3D printing
4/5/22 | Meeting | 3:00 pm – 4:00 pm | PGCLL | Louisa Mueller, Muhammad Khan, Wendong Wang, Marisa Patel | Final preparatio n | -assigned the parts for presentation -discussed about future refinements of the design
4/6/22 | Meeting | 8:30 pm – 9:00 pm | Microsoft teams | Louisa Mueller, Muhammad Khan, | Video recording | -recorded the video before presentation

| | | | Wendong Wang, Marisa Patel | | -finished up presentation PowerPoint
4/7/22 | Presentation Prep | 3:50 pm – 4:30 pm | ABB-C419 | Louisa Mueller, Muhammad Khan, Wendong Wang, Marisa Patel | Final presentati on | -final presentation
4/11/2 2 | Meeting | 7:00 pm – 7:30 pm | Microsoft teams | Louisa Mueller, Muhammad Khan, Wendong Wang, Marisa Patel | Final deliverabl es pack up | -packed up the final deliverables

Appendix C – Weekly Meetings

Weekly Design Studio Agendas and Meeting Minutes

Tuesday March 1, 2022:
1. Attendance and Updates
- Everyone is present
- First met of the team
- Introduction to the project
1. Meeting Minutes and Milestone Work (Milestone 0&1)
- Completion of client notes
- Finish the initial problem statement
- Use the objective tree to demonstrate the requirements of the client
- Determine the three main objectives: ergonomic, lightweight, adaptive
- Collect the abilities of each team members to use specific skills to deal with the problem
1. To be done after class
- Complete the Gantt chart and client notes
1. Notes for next week
- Focus on the research assignment next week

Tuesday, Thursday March 8, 10, 2022:
1. Attendance and Updates
- Everyone is present
- Start work on sketches
- Ask help for final function for morph chart
1. Meeting Minutes and Milestone Work (Milestone 2)
- 1. Finish the compiled second client notes
- 2. Determine the specific target – cutting with a knife
- 3. Finish the individual research assignments
- 4. Finish the functional analysis
- 5. Complete the refined problem statement
- 6. Explore more concepts and sketch them
1. To be done after class
- Complete the initial prototype of the design.
1. Notes for next week
- There will be design reviews from science students on Thursday to give feedback to our designs.

Tuesday, Thursday March 15, 17 2022
1. Attendance and Updates

- Everyone is present
1. Meeting Minutes and Milestone Work (Milestone 3)
- 1. Finish the initial prototype of the designs
- 2. discuss and collect pros and cons of the designs
- 3. complete the decision matrix
- 4. Finish the design interview from the science students and gain feedback
- 5. decide on the materials of the designs (filament of 3D printing – 0.2 mm PLA – quite food-safe)
- 6. think about ways to remove the knife after cutting stuff
- 7. Need to think about the positions, size and alignment of the blades of concept 2.
- 8. Methods to clean the boards and blades.
1. To be done after class
- Come up with the resolutions corresponding to the feedback
1. Notes for next week
- Pick one concept to work on next week

Tuesday, Thursday March 22, 24 2022
1. Attendance and Updates
- Everyone is present
1. Meeting Minutes and Milestone Work (Milestone 4)
- 1. Refine the initial prototype
- 2. Build the actual physical design
- 3. Make a test plan
- 4. In the design review, ask for feedback for the refined design
- 5. Review of the design:
- 1) make some kind of button instead of pulling the blades out
- 2) suction or gravity (how the board is fixed on the table (rubber dots, etc.)
- 3) all the food will remain under the blade after cutting
- 4) The design is useful for the client
- 5) the client needs to lift the board up to get the food slices after cutting them.
- 6) make the board higher from the table
- 7) the container can be designed to slide in or out
- 8) easy to cut himself when putting the blade in or out. (find an easy way to pull them out)
- 9) find ways to prevent the client from getting hurt
- 10) figure out the dimensions of the blades and board
- 11) The client has finger dislocation problems so when sliding the blades he might hurt himself.
- 12) The dimensions (height) of the board might cause issues to the client’s elbows and shoulders ( the elbows cannot be positioned too high – or can rest )
1. To be done after class
- Finish the milestone 4 worksheet
- Refine the prototype
1. Notes for next week
- Refine the prototype and figure out the blade problem

Tuesday, Thursday March 29, 31 2022
1. Attendance and Updates
- Everyone is present

1. Meeting Minutes and Milestone Work
- 1. Refined the design and discussed some specific dimensions
- 2. Focusing on the report
- 3. Prepare for the pitch presentation
- 4. Made sure that only blades needs 3D printing
•
1. To be done after class
- Create a solid model for the design
1. Notes for next week
- Discuss about the final deliverable and pitch interview
- Refine the final prototype and create a solid model

Tuesday April 5, 2022
1. Attendance and updates
a. Everyone is present
1. Meeting minutes
a. Completed the PowerPoint for presentation
a. Completed the final deliverables
a. Assigned the presentation parts
a. Discussed about the improvements of the design
1. Updates
a.

Wednesday April 6, 2022
1. Attendance and updates
a. Everyone is present
1. Meeting minutes
a. Finished recording the video for demonstration
1. Updates
a. none

Monday April 11, 2022

### 1. Attendance and Updates

- Everyone is present

### 2. Meeting Minutes and Milestone Work

- 1. Packing up the final deliverables
1. To be done after class
- None
1. Notes for next week
- None

Appendix D – Worksheets

Milestone 0 Team

Milestone 1 Team

Milestone 2 Team

Milestone 3 Team

Milestone 4 Team

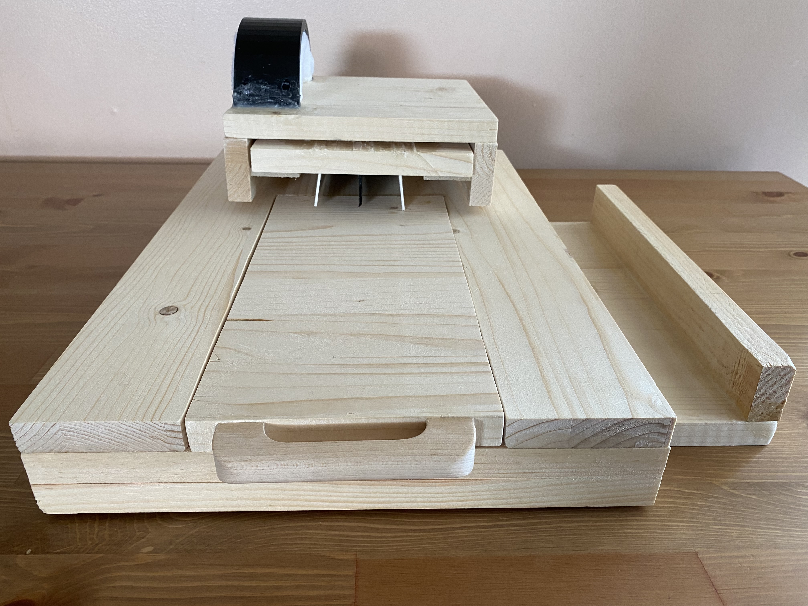
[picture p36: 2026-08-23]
Design/Physical Model/Front_View_Closed_Position.jpg

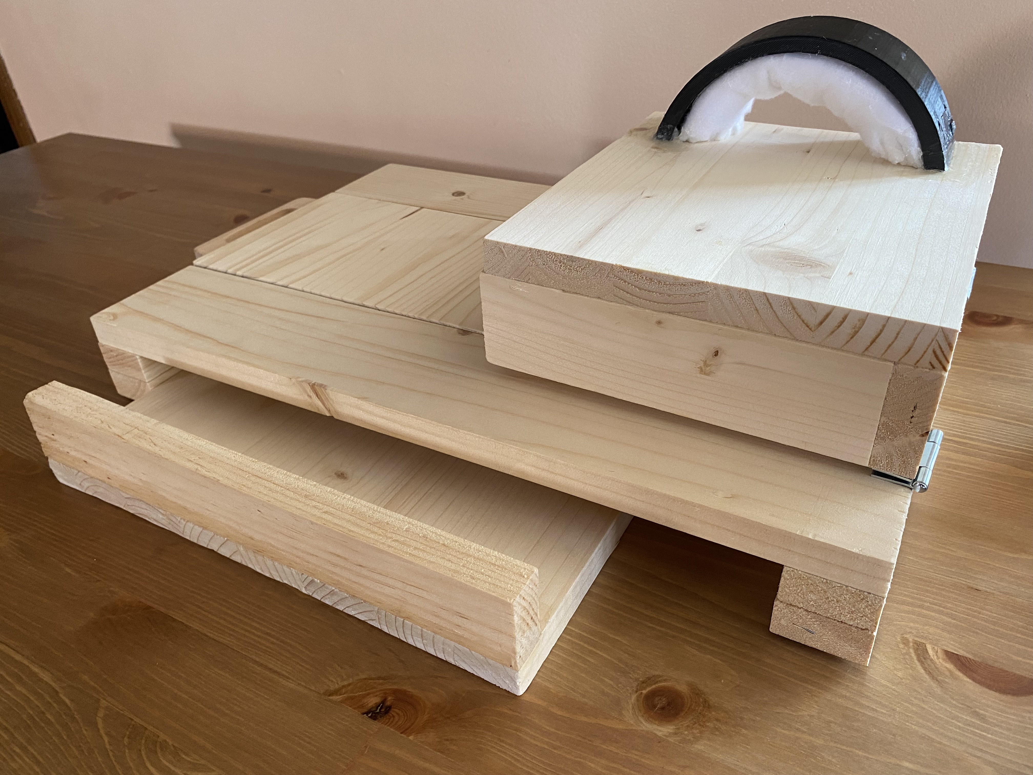
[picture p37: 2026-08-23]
Design/Physical Model/Right_Corner_View_Closed_Position.jpg

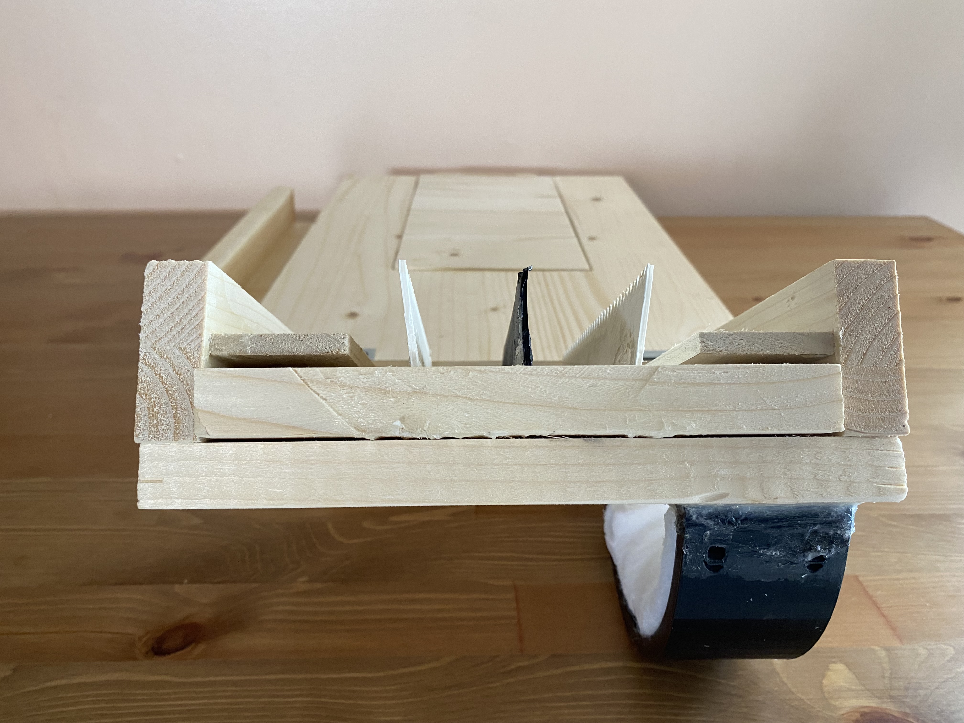
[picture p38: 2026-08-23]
Design/Physical Model/Back_View_Opened_Position.jpg

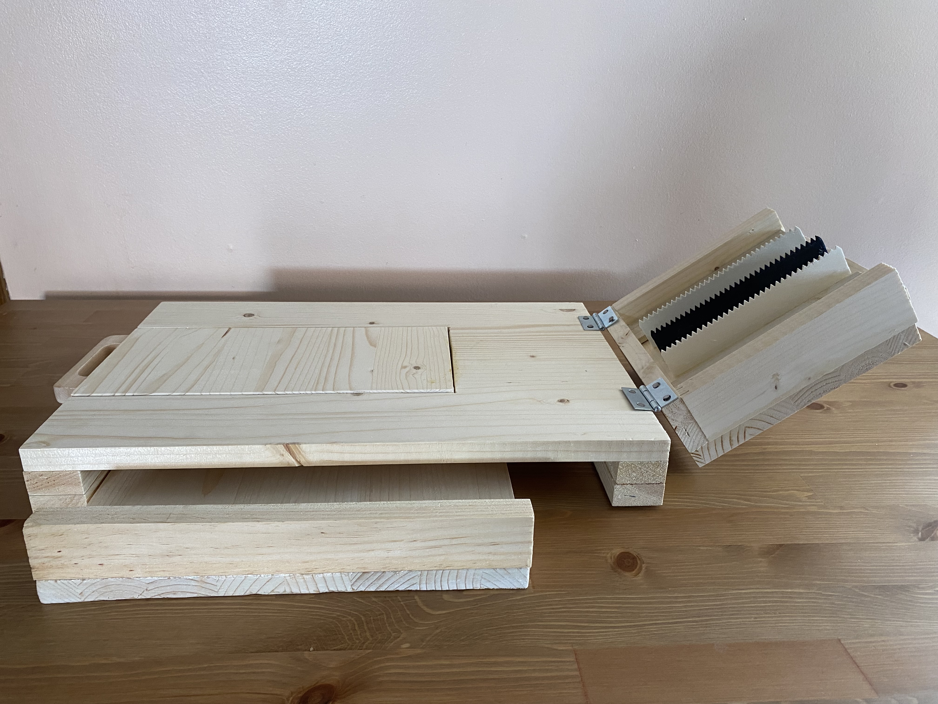
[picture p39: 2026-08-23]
Design/Physical Model/Right_View_Opened_Position.jpg

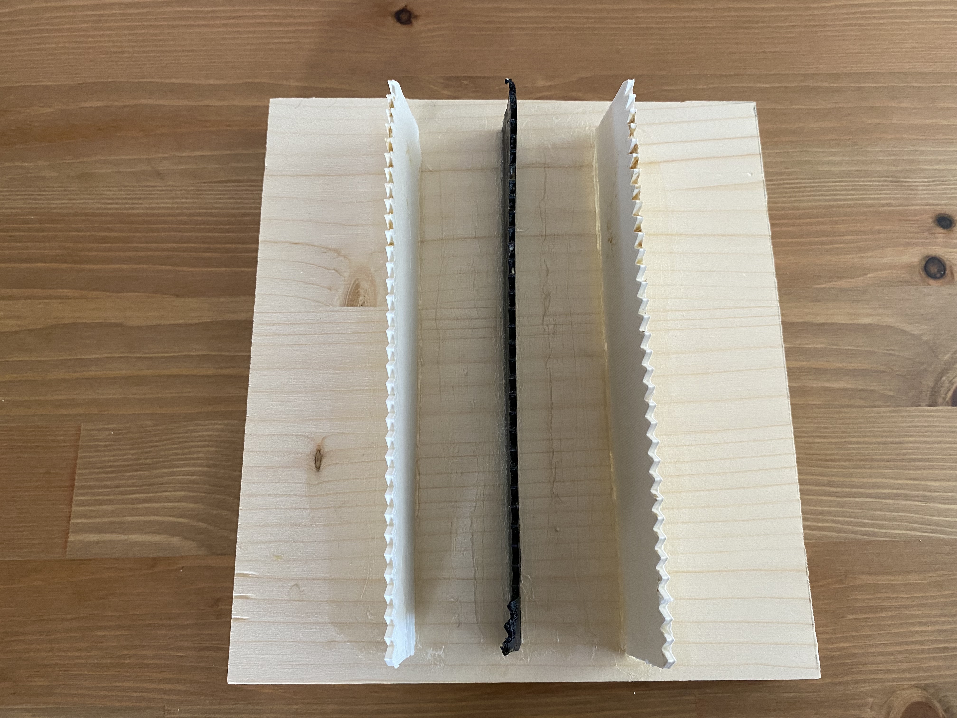
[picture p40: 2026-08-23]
Design/Physical Model/Blade_Insert.jpg

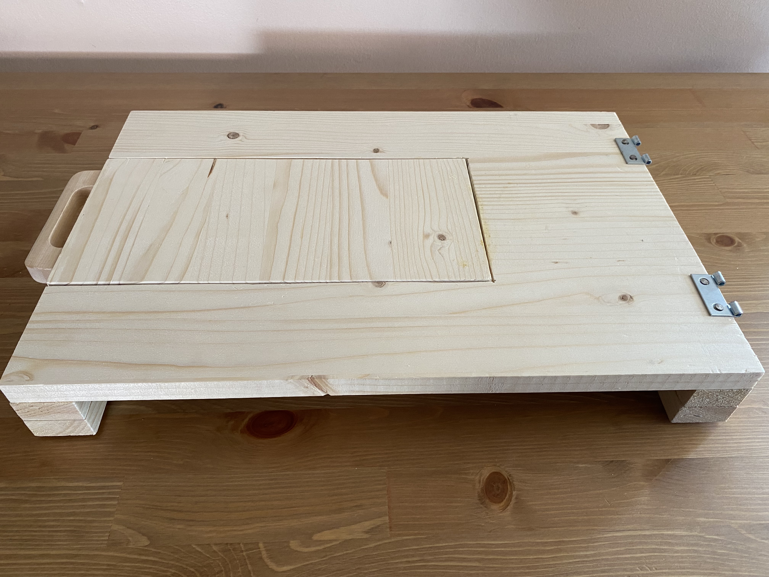
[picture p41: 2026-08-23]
Design/Physical Model/Cutting_Board_with_Cutout.jpg

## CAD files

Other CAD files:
Design/CAD Files/Assembly of Parts.iam
Design/CAD Files/Blade Insert.ipt
Design/CAD Files/Blade.ipt
Design/CAD Files/Cutting Board Cutout.ipt
Design/CAD Files/Cutting Board without Cutout.ipt
Design/CAD Files/Drawer.ipt
Design/CAD Files/Hinge Bottom.ipt
Design/CAD Files/Hinge Pin.ipt
Design/CAD Files/Hinge Top.ipt
Design/CAD Files/Slicer Strap.ipt
Design/CAD Files/Slicer.ipt
